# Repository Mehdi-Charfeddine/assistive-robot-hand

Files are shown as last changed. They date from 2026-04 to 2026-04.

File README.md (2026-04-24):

# Assistive Roboterhand (Arduino-basiert)

## Übersicht
Dieses Projekt befasst sich mit der Entwicklung einer steuerbaren Roboterhand, die menschliche Fingerbewegungen erfasst und in Echtzeit auf eine mechanische Hand überträgt.

Das System unterstützt sowohl einen **kabelgebundenen als auch drahtlosen Betrieb** und eignet sich für Anwendungen in den Bereichen:
- Mensch-Maschine-Interaktion  
- Teleoperation  
- Assistive Systeme  

---

## Hauptfunktionen
- Echtzeit-Erfassung von Fingerbewegungen mittels Flexsensoren  
- Unabhängige Steuerung von fünf Fingern  
- Kabelgebundene und drahtlose Steuerung  
- Gestenerkennung und -validierung  
- Greifen und Halten von Objekten (< 200 g)  

---

## Systemaufbau
Das System besteht aus:
- Einem **Handschuh mit integrierten Flexsensoren**  
- Einer **Steuereinheit auf Basis eines Mikrocontrollers (Arduino)**  
- Einer **mechanischen Roboterhand mit Aktoren (Servomotoren)**  
- Einer drahtlosen Kommunikationskomponente (ab Sprint 2)  

---

## Entwicklungsprozess (Scrum)

### Sprint 1 – Kabelgebundene Steuerung
- Umsetzung der Fingerbewegungserkennung mittels Flexsensoren  
- Echtzeit-Übertragung auf die Roboterhand  
- Grundlegende Fingerbewegungen (Beugen und Strecken)  

### Sprint 2 – Drahtlose Kommunikation
- Implementierung einer drahtlosen Datenübertragung (≥ 2 m Reichweite)  
- Reduzierung der Latenz (< 200 ms)  
- Erkennung und Validierung von Handgesten  

### Sprint 3 – Interaktion mit Objekten
- Greifen von zylindrischen und kugelförmigen Objekten  
- Halten von Objekten (< 200 g) für mindestens 30 Sekunden  
- Optimierung von Greifkraft und Oberflächen der Fingerspitzen  

---

## Technologien & Tools
- Arduino / Embedded Systems  
- Flexsensoren  
- Servomotoren (Aktorik)  
- Drahtlose Kommunikationsmodule  
- CAD (2D & 3D Konstruktion)  
- Mechanisches Prototyping  

---

## Eigener Beitrag
- Vollständige **2D- und 3D-Konstruktion** der Roboterhand  
- Erstellung technischer Zeichnungen und CAD-Modelle  
- Unterstützung bei **Fertigung, 3D-Druck und Montage**  
- Mitarbeit bei Systemdiagrammen und technischer Dokumentation  
- **Projektplanung und Zeitmanagement** im Scrum-Prozess  

---

## Dokumentation
Das Projekt umfasst:
- Lastenheft  
- Pflichtenheft  
- Technische Spezifikationen  
- Sprint-Dokumentation (Sprint 1–3)  
- Systemdiagramme  

---

## Hinweis
Dieses Projekt wurde im Rahmen eines Teamprojekts an der HTW Berlin entwickelt.

---

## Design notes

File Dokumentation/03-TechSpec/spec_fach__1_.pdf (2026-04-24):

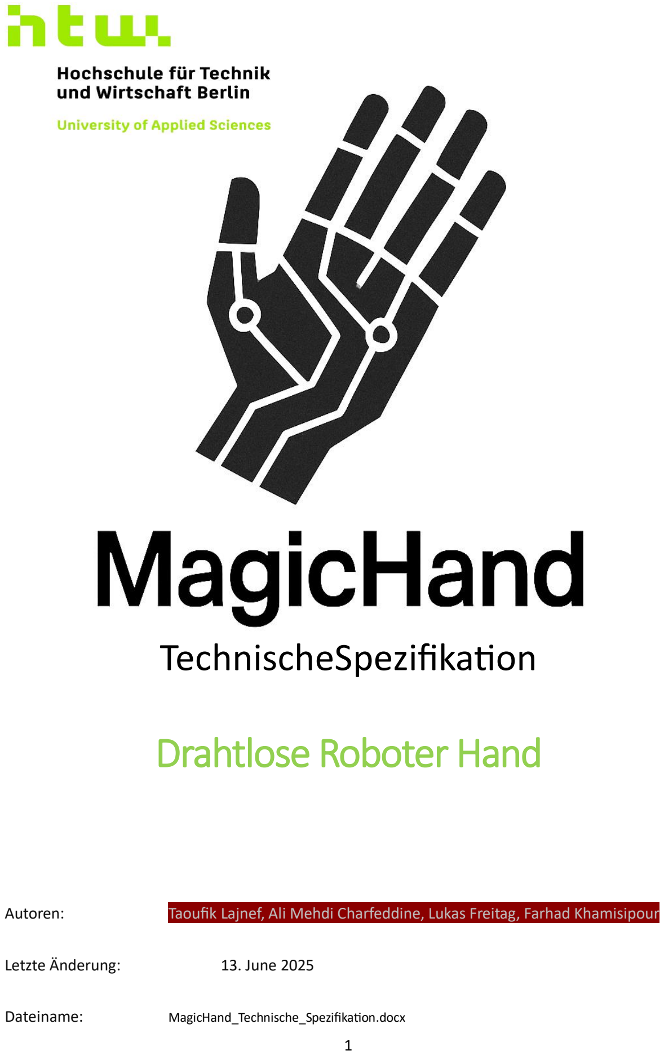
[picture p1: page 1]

1

# TechnischeSpezifikation

# Drahtlose Roboter Hand

Autoren: | Taoufik Lajnef, Ali Mehdi Charfeddine, Lukas Freitag, Farhad Khamisipour
Letzte Änderung: | 13. June 2025
Dateiname: | MagicHand_Technische_Spezifikation.docx

2

## Table of Contents

3

4

5

## Abbildungsverzeichnis

6

Copyright

© HTW Berlin - Projektteam MagicHand 2025

Die Weitergabe, Vervielfältigung oder anderweitige Nutzung dieses Dokumentes oder Teile

davon ist unabhängig vom Zweck oder in welcher Form untersagt, es sei denn, die

Rechteinhaber haben ihre ausdrückliche schriftliche Genehmigung erteilt.

Version Historie

Version | Datum | Verantwortlich | Änderung
0.1 | 28.05.2025 | Projektteam | Initiale Dokumenterstellung
0.2 | 01.06.2025 | Projektteam | Hardware-Spezifikation erweitert
0.3 | 03.06.2025 | Projektteam | Software-Architektur finalisiert
1.0 | 04.06.2025 | Projektteam | Sprint 1 Spezifikation abgeschlossen

7

# 1. Vorhandene Dokumente

Dokument | Autor | Datum
MagicHand_lastenheft.docx | Projektteam | 24.04.2025
MagicHand_Pflichtenheft.docx | Projektteam
Technische_Spezifikation-Muster (HTW Berlin) | Prof. Abuosba | 30.09.2015
3D-Konstruktionsmodell.ipt | | 25.05.2025
Arduino Libraries Dokumentation | Arduino.cc | aktuell

# 2. Prozessüberblick

Der Prozessüberblick für Sprint 1 zeigt die vollständige Kette von der Benutzereingabe bis zur mechanischen Roboterhandbewegung. Das System arbeitet in Echtzeit und nutzt eine kabelgebundene Architektur für maximale Zuverlässigkeit und minimale Latenz. Die Implementierung konzentriert sich auf die fundamentalen Bewegungsübertragungsfunktionen, die als Grundlage für alle zukünftigen Erweiterungen dienen.

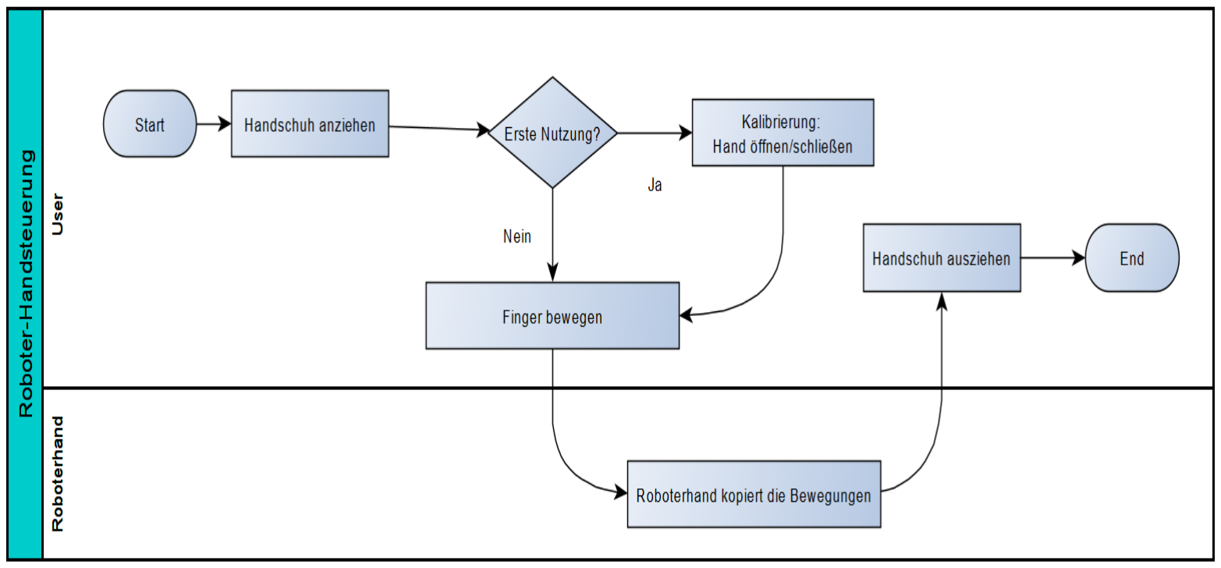
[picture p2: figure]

8

## 2.1. Fachlicher Workflow

Figure 1 Fachlicher Workflow

Der fachliche Workflow beginnt mit dem Anziehen des Sensorhandschuhs, der mit fünf hochpräzisen Flexsensoren ausgestattet ist. Diese Sensoren sind strategisch an den Fingerrücken positioniert, um optimale Bewegungserkennung bei minimalem Tragekomfort-Verlust zu gewährleisten. Der Handschuh verwendet atmungsaktive Materialien und ein ergonomisches Design, das auch bei längerer Nutzung angenehm zu tragen ist.

Die Systemkalibrierung ist ein entscheidender Schritt, der die individuellen anatomischen Unterschiede zwischen Benutzern berücksichtigt. Das System führt den Benutzer durch eine strukturierte Kalibrierungssequenz, bei der verschiedene Handhaltungen erfasst werden. Diese Daten werden im EEPROM gespeichert und ermöglichen eine personalisierte, hochpräzise Bewegungserkennung.

Während des normalen Betriebs erfasst das System kontinuierlich die Fingerbewegungen mit einer Frequenz von 50Hz. Jede Bewegung wird in Echtzeit analysiert, gefiltert und an die entsprechenden Servomotoren weitergeleitet. Das System unterscheidet zwischen verschiedenen Bewegungsarten: präzise Einzelfingerbewegungen (UC-1) und koordinierte Handbewegungen wie Öffnen und Schließen (UC-2).

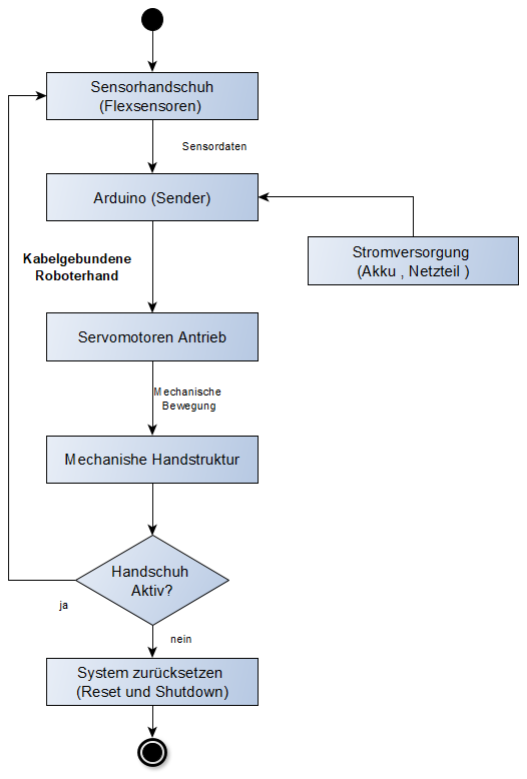
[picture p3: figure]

9

## 2.2. Technischer Workflow

Figure 2 Grober technischer Workflow

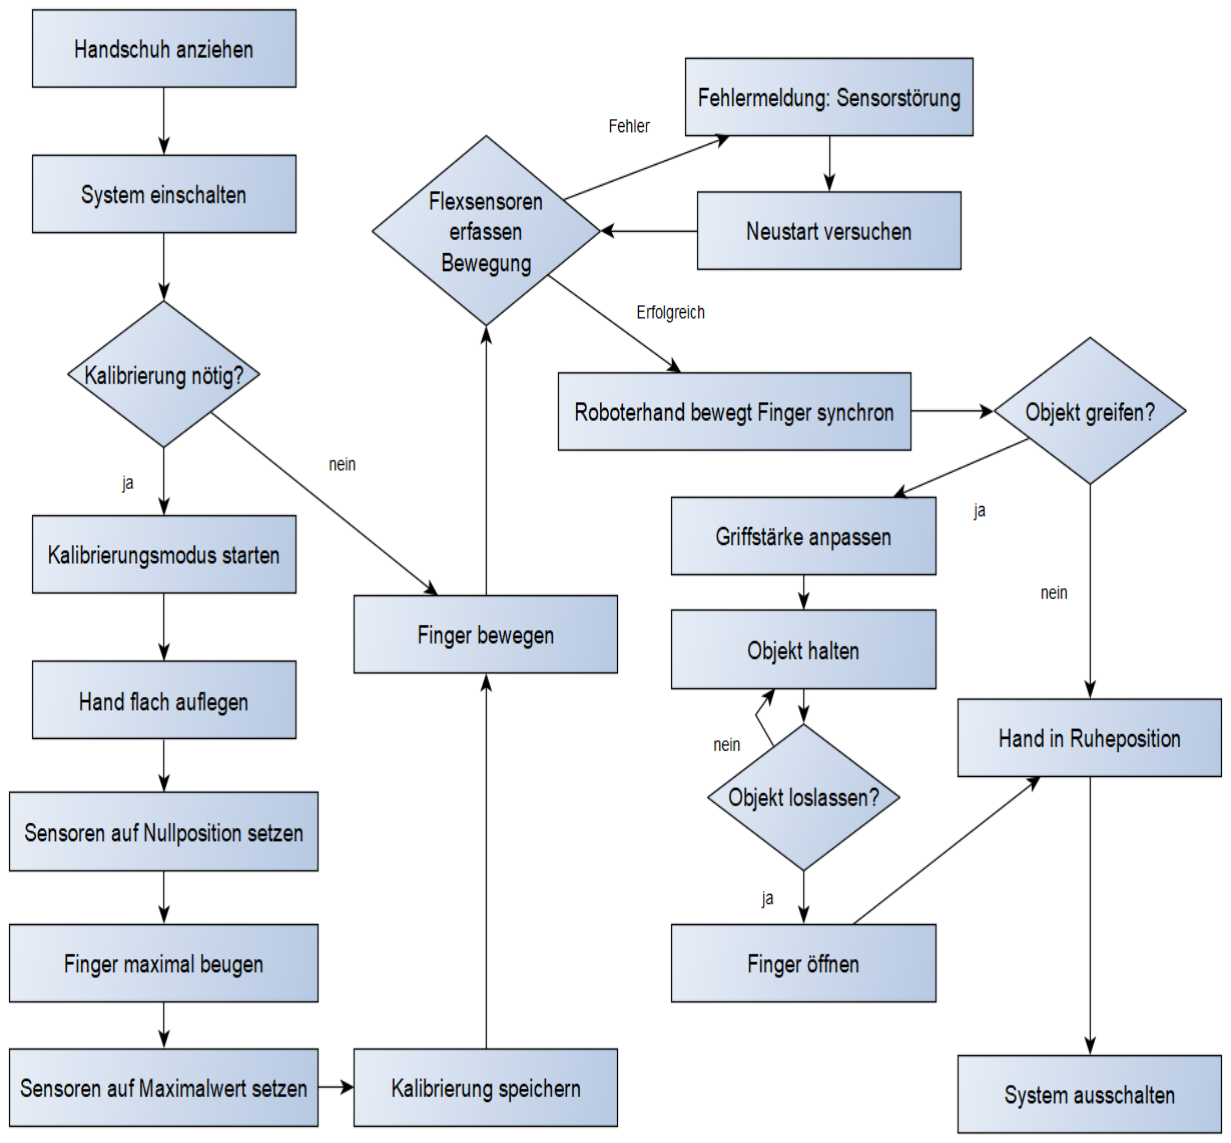
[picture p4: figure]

10

Der technische Workflow zeigt die detaillierte Datenverarbeitung von der Sensorerfassung

bis zur mechanischen Ausgabe. Das System verwendet eine modulare Architektur, die eine

klare Trennung zwischen Datenerfassung, Verarbeitung und Ausgabe ermöglicht.

Figure 3 Feiner technischer Workflow

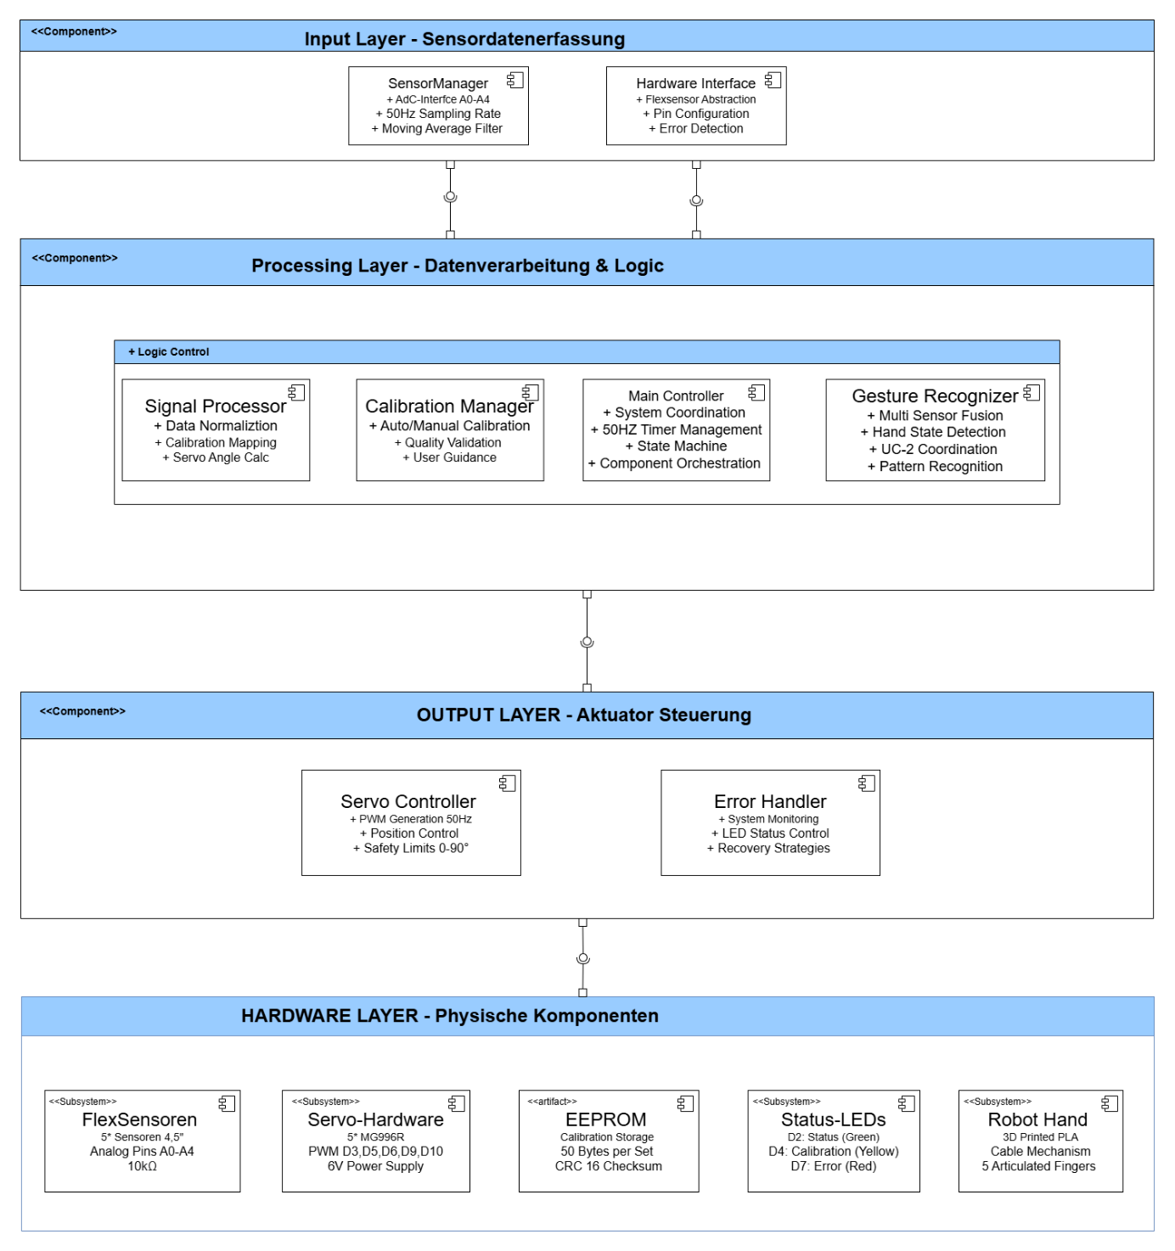
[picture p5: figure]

11

# 3. Technische Spezifikation SW

## 3.1. Überblick Komponenten

Figure 4 Komponentendiagramm

12

Pin-Belegung:

Analog Inputs: A0-A4 (Flexsensoren)

PWM Outputs: D3,D5,D6,D9,D10 (Servos)

Digital: D2 (Status-LED), D7 (Kalibrierungs-Button)

IT-Komponente | Erfasste Funktion aus dem Pflichtenheft
SensorManager | UC-1: Fingerbewegung übertragen
SignalProcessor | UC-1: Analog-Digital-Wandlung & Filterung
ServoController | UC-1: Servo-Ansteuerung
| UC-2: Hand öffnen/schließen
CalibrationManager | Sensor-Kalibrierung (Min/Max-Werte)
MainController | Koordination aller Module

13

## 3.2. Beschreibung der Implementierung

## 3.2.1. UC-1: Fingerbewegung übertragen

# | Komponentendetail | Erforderliche Arbeiten

T1 | Hardware-Interface | Flexsensor-Spannungsteiler, ADC-Konfiguration
T2 | SensorManager | Analog-Wert-Erfassung, Rauschfilterung
T3 | SignalProcessor | Normalisierung, Kalibrierung, Servo-Mapping
T4 | ServoController | PWM-Generierung, Position-Control

T1: Hardware-Interface

- Schaltungsdesign: 5x Spannungsteiler (Flexsensor + 10kΩ Pulldown)
- ADC-Konfiguration: 10-Bit Auflösung, 5V Referenzspannung
- Pin-Mapping: A0-A4 für Sensoren, D3,D5,D6,D9,D10 für Servos
- Stromversorgung: 5V für Sensoren, separate 6V für Servos

T2: SensorManager

- Funktionsumfang: Kontinuierliche Sensorabfrage (50Hz)
- Implementierte Methoden:

cpp

int readFlexSensor(int pin);

14

int applyFilter(int rawValue, int sensorIndex);

bool validateSensorRange(int value);

- Filteralgorithmus: Moving Average über 3 Samples
- Exception Handling: Sensor-Ausfall-Erkennung, Fallback-Werte

T3: SignalProcessor

- Business Logic: Analog-zu-Position-Transformation
- Kalibrierungsalgorithmus:

cpp

void calibrateSensor(int sensorIndex);

int normalizeValue(int raw, int min, int max);

int mapToServoAngle(int normalized);

- Input: ADC-Werte (0-1023)
- Output: Servo-Positionen (0-180°)
- Verhalten: Echtzeit-Verarbeitung mit <20ms Latenz

T4: ServoController

- Servo-Bibliothek: Standard Arduino Servo.h
- PWM-Konfiguration: 50Hz, 1-2ms Pulsbreite
- Positionssteuerung:

cpp

void updateServoPosition(int servoIndex, int angle);

void synchronizeAllServos();

15

bool checkServoLimits(int angle);

- Exception Handling: Überlastschutz, Position-Limits

## 3.2.2. UC-2: Hand öffnen/schließen

# | Komponentendetail | Erforderliche Arbeiten

T5 | GestureRecognizer | Erkennung koordinierter Handbewegungen
T6 | ServoController | Synchrone Ansteuerung aller Servos
T7 | PositionManager | Vordefinierte Positionen (offen/geschlossen)
T8 | StateManager | Zustandsüberwachung der Gesamthand

T5: GestureRecognizer

- Erkennungslogik: Simultane Analyse aller 5 Sensoren
- Schwellenwerte: Offen >80%, Geschlossen <20%
- Implementierung:

cpp

HandState detectHandState();

bool isHandOpening();

bool isHandClosing();

T6: ServoController (erweitert)

- Synchronisations-Funktionen:

cpp

16

void openHand();

void closeHand();

void setAllServos(int angles[5]);

- Timing: Koordinierte Bewegung über 500ms

T7: PositionManager

- Vordefinierte Positionen:
- Offen: [0°, 0°, 0°, 0°, 0°]
- Geschlossen: [90°, 90°, 90°, 90°, 90°]
- Interpolation: Sanfte Übergänge zwischen Positionen

T8: StateManager

- Zustandsüberwachung: Tracking der aktuellen Handposition
- Error Handling: Inkonsistente Sensordaten, mechanische Blockaden

## 3.2.3. Kalibrierungs-System

# | Komponentendetail | Erforderliche Arbeiten

T9 | CalibrationManager | Automatische und manuelle Kalibrierung
T10 | EEPROMStorage | Persistente Speicherung der Kalibrierdaten
T11 | CalibrationUI | Benutzer-geführte Kalibrierungs-Routine
T12 | ValidationModule | Überprüfung der Kalibrierungs-Qualität

T9: CalibrationManager

- Kalibrierungs-Modi:

cpp

17

void startAutoCalibration();

void startManualCalibration();

bool validateCalibration();

void resetCalibration();

- Algorithmus: Min/Max-Erfassung über 10 Bewegungszyklen
- Adaptivität: Benutzer-spezifische Anpassung

T10: EEPROMStorage

- Datenpersistierung:

cpp

void saveCalibrationData(CalibrationData data);

CalibrationData loadCalibrationData();

bool isCalibrationValid();

- Speicherorganisation: 50 Bytes pro Sensor-Set
- Versionierung: Kalibrierungs-Timestamp und Checksum

## 3.2.4. Error-Handling und Recovery

# | Komponentendetail | Erforderliche Arbeiten

T13 | ErrorDetection | Kontinuierliche System-Überwachung
T14 | RecoveryManager | Automatische Fehlerbehandlung
T15 | SafetyModule | Schutz vor Hardware-Schäden
T16 | DiagnosticsLog | Fehler-Protokollierung und Analyse

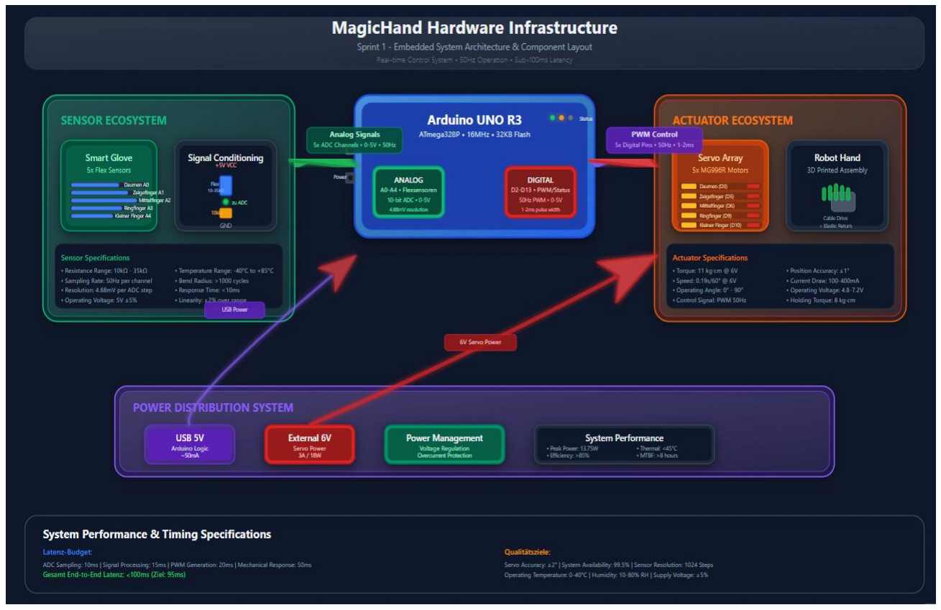
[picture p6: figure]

18

## 3.3. System Infrastruktur

Figure 5 Systeminfrastruktur

Hardware-Infrastruktur:

- Entwicklungsboard: Arduino UNO R3
- Sensorik: 5x Flexsensor 2.2", 5x 10kΩ Widerstände
- Aktuatorik: 5x Servo MG996R
- Verkabelung: Breadboard, Jumper-Kabel, Prototyping-Aufbau
- Stromversorgung: USB (5V) + externes Netzteil (6V, 3A)

Software-Infrastruktur:

- Entwicklungsumgebung: Arduino IDE ≥ 2.0
- Compiler: AVR-GCC
- Bibliotheken: Servo.h, EEPROM.h
- Debugging: Serial Monitor, LED-Status-Anzeigen

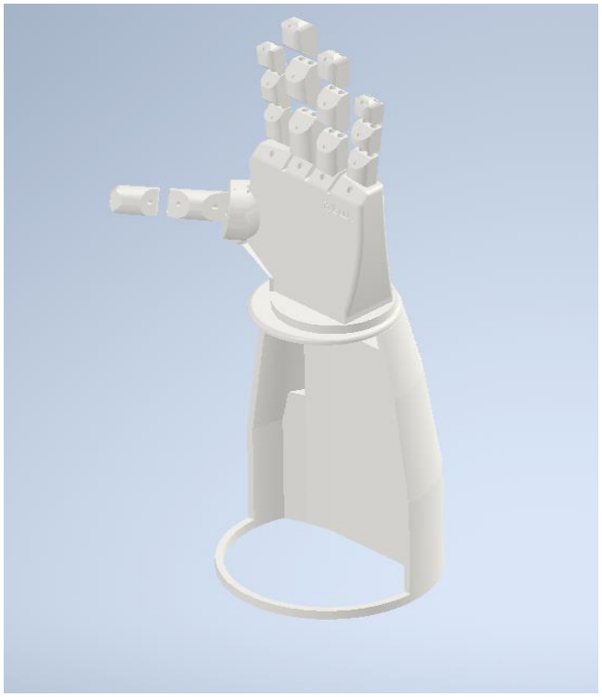
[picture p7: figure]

19

# 4. Technische Spezifikation Hardware

## 4.1. Baugruppen

Figure 6 3D Inventor Baugruppe

Die mechanischen Hauptbaugruppen:

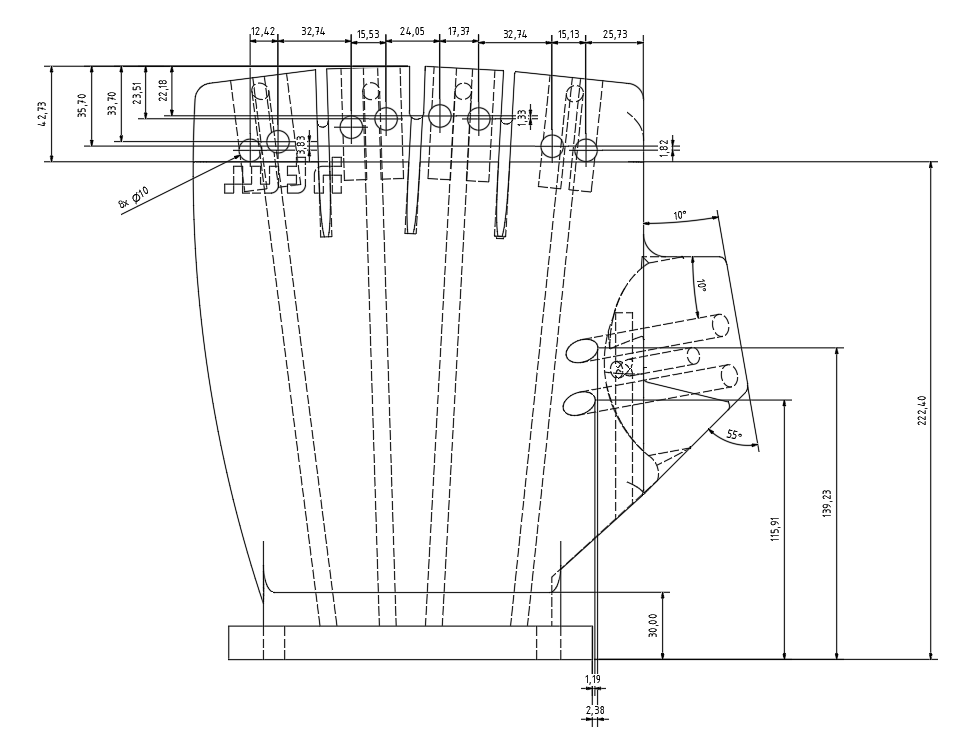
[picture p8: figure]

20

1. Roboterhand-Chassis: 3D-gedruckte Handfläche mit Servo-Befestigungen
2. Finger-Module: 5x bewegliche Fingergelenke mit Seilführung
3. Sensor-Handschuh: Flexsensor-Integration in Textilhandschuh
4. Elektronik-Träger: Arduino und Breadboard-Halterung

## 4.2. Einzelteile

Figure 7 Hand

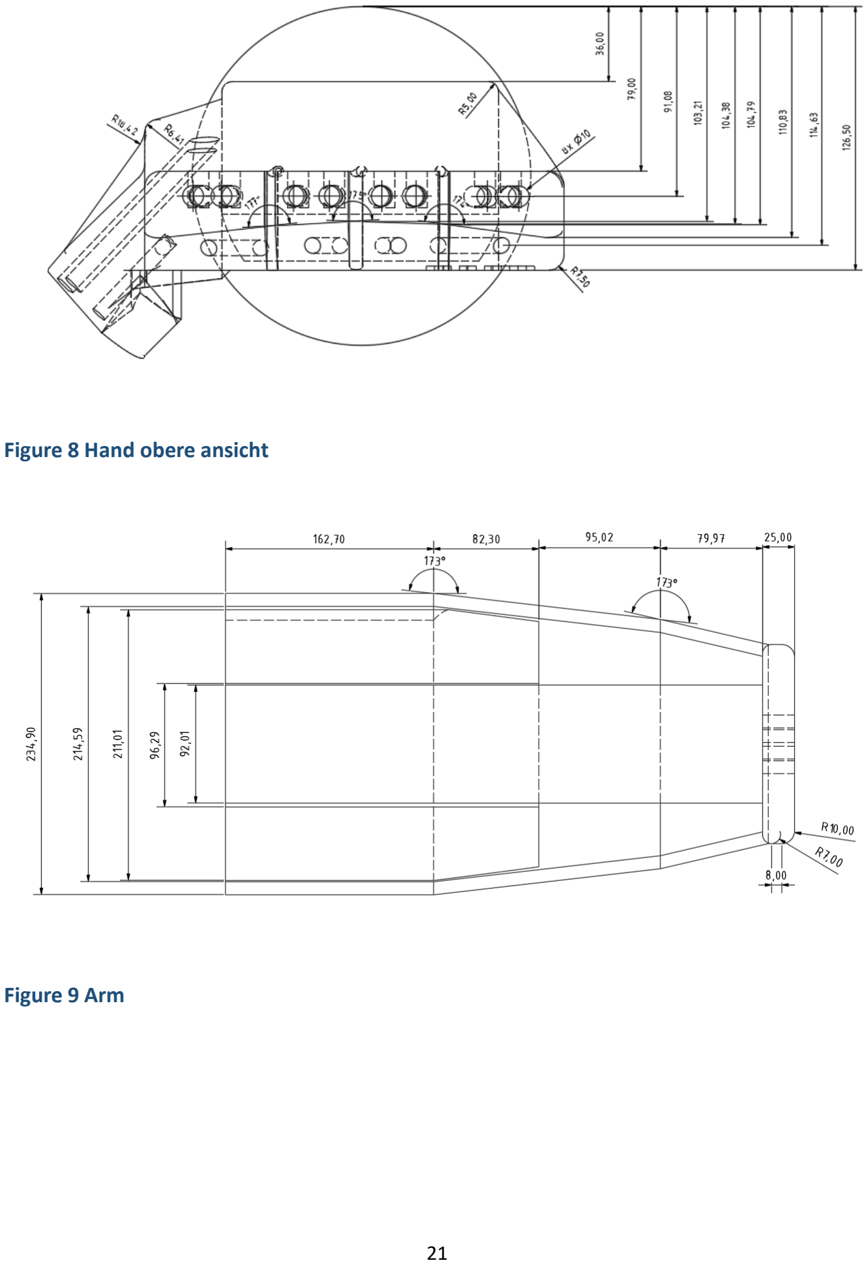
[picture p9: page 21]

21

Figure 8 Hand obere ansicht

Figure 9 Arm

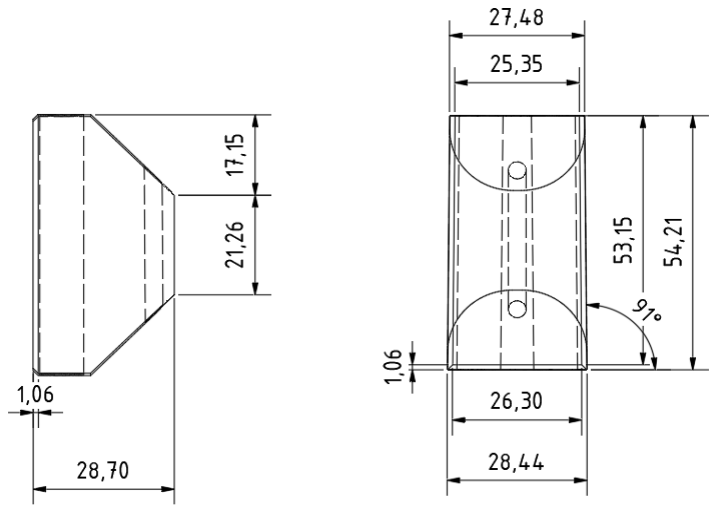
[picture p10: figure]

22

Figure 10 Finger Mittelglied

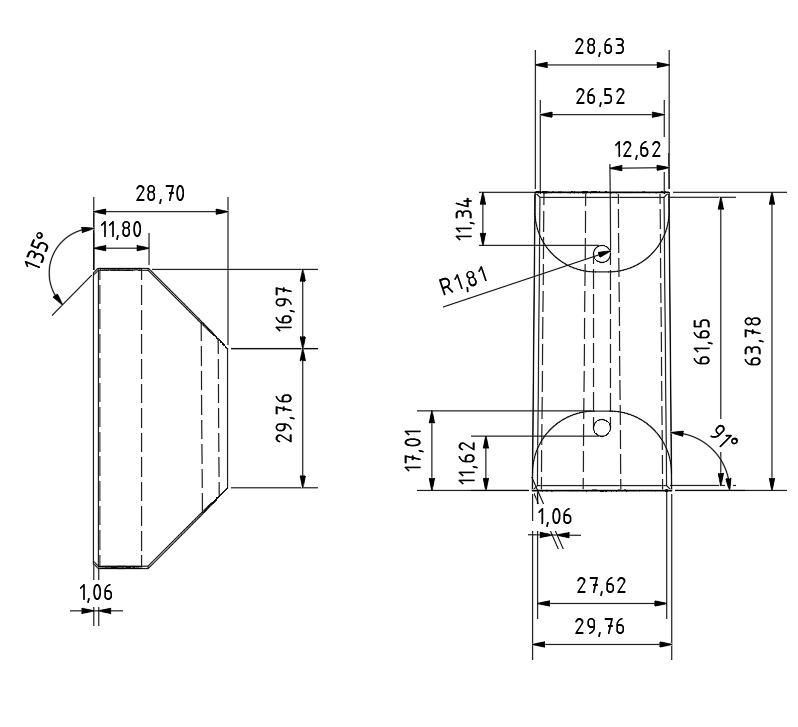
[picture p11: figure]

23

Figure 11 Finger Grundglied

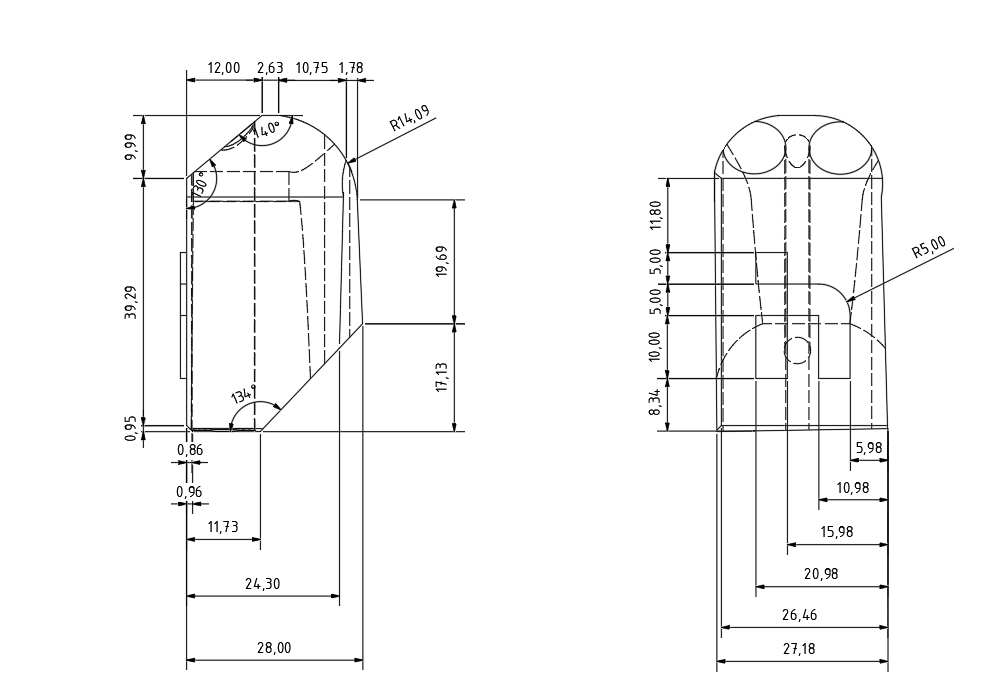
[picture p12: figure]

24

Figure 12 Endglied

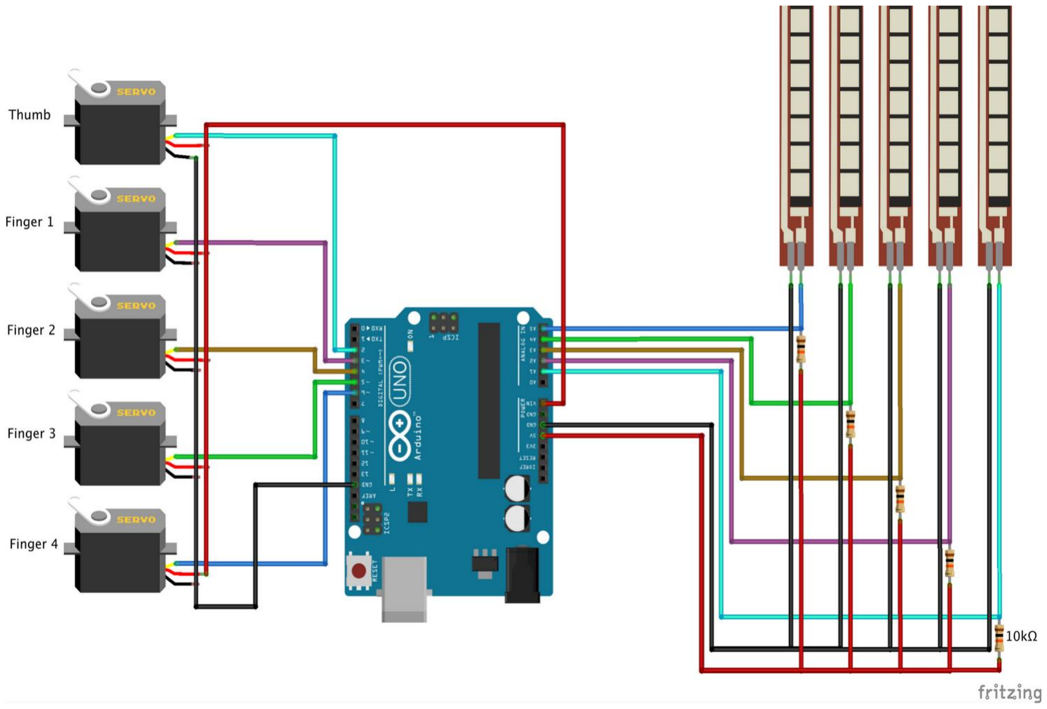
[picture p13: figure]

25

Technische Zeichnungen der Einzelteile:

Finger-Segment:

- Material: PLA, 30% Infill
- Abmessungen: 40mm x 15mm x 10mm
- Features: Seil-Durchführungen, Gelenk-Aufnahmen

Servo-Halterung:

- Material: PETG (höhere Festigkeit)
- Befestigung: M3 Schrauben
- Seil-Umlenkung: Integrierte Führungsrollen

Figure 13 Schaltplan Flexsensor-Interface

26

27

## 4.3. Berechnungen

Mechanische Berechnungen für Sprint 1:

Servo-Kraft-Berechnung:

- Benötigtes Drehmoment pro Finger: ~2 kg⋅cm
- MG996R Spezifikation: 11 kg⋅cm (6V)
- Sicherheitsfaktor: 5x → ausreichend dimensioniert

Seil-Mechanik:

- Seilzug-Verhältnis: 1:1 (direkter Zug)
- Nylon-Angelschnur: Zugfestigkeit >10N
- Elastisches Rückstellseil: Federkonstante ~0.5 N/mm

Stromverbrauch-Berechnung:

- 5x Servo im Stillstand: 5 x 50mA = 250mA
- 5x Servo unter Last: 5 x 400mA = 2A
- Arduino UNO: ~50mA
- Gesamtverbrauch: <2.5A bei 6V

28

# 5.User Interface & Bedienung

## 5.1. Status-Anzeigen

LED-Status-System:

LED-Farbe | Zustand | Bedeutung | Pin
Grün | Dauerlicht | System bereit, Kalibrierung OK | D2
Grün | Blinken (1Hz) | Normaler Betrieb, Datenübertragung | D2
Gelb | Dauerlicht | Kalibrierung erforderlich | D4
Gelb | Blinken (2Hz) | Kalibrierung läuft | D4
Rot | Dauerlicht | Kritischer Fehler, System gestoppt | D7
Rot | Blinken (5Hz) | Sensor-Fehler oder Servo-Überlast | D7

## 5.2. Kalibrierungs-Interface

Kalibrierungs-Button (Pin D8):

- Kurzer Druck (< 1s): Status-Ausgabe über Serial
- Langer Druck (> 3s): Kalibrierungs-Routine starten
- Sehr langer Druck (> 10s): Kalibrierung zurücksetzen

Kalibrierungs-Ablauf:

1. Button-Press erkannt → Gelbe LED blinkt
2. "Spreizen Sie alle Finger vollständig" → 5s Erfassung
3. "Schließen Sie alle Finger vollständig" → 5s Erfassung

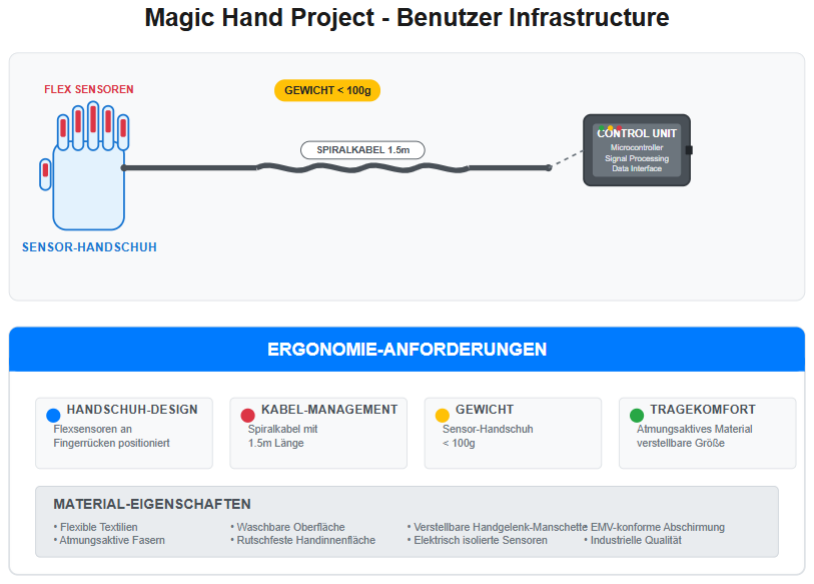
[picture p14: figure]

29

4. "Bewegen Sie alle Finger 3x" → 10s Erfassung
5. Validierung und EEPROM-Speicherung
6. Grüne LED → Kalibrierung erfolgreich

## 5.3. Benutzerinteraktion

Figure 14 User Interface Layout

Ergonomie-Anforderungen:

- Handschuh-Design: Flexsensoren an Fingerrücken positioniert
- Kabel-Management: Spiralkabel mit 1.5m Länge
- Gewicht: Sensor-Handschuh < 100g
- Tragekomfort: Atmungsaktives Material, verstellbare Größe

30

# 6. Performance-Spezifikation

## 6.1. Latenz-Anforderungen

End-to-End Latenz-Budget:

Komponente | Ziel-Latenz | Max-Latenz | Messmethode
Sensor-Abtastung | 10ms | 20ms | ADC-Timing
Signal-Verarbeitung | 15ms | 25ms | Code-Profiling
Servo-Ansteuerung | 20ms | 30ms | PWM-Response
Mechanische Bewegung | 50ms | 80ms | Video-Analyse
Gesamt-Latenz | 95ms | 155ms | Oszilloskop

## 6.2. Genauigkeits-Metriken

Positionierungs-Genauigkeit:

- Servo-Auflösung: 180° / 1024 Steps = 0.175° pro Step
- Ziel-Genauigkeit: ±2° (entspricht ±11 ADC-Steps)
- Wiederholgenauigkeit: ±1° bei identischer Eingabe
- Linearität: R² > 0.95 zwischen Eingabe und Ausgabe

## 6.3. Zuverlässigkeits-Kriterien

Verfügbarkeits-Anforderungen:

- MTBF (Mean Time Between Failures): > 8 Stunden Dauerbetrieb
- MTTR (Mean Time To Recovery): < 30 Sekunden bei Soft-Errors
- Erfolgsrate: > 99% erfolgreiche Bewegungsübertragungen

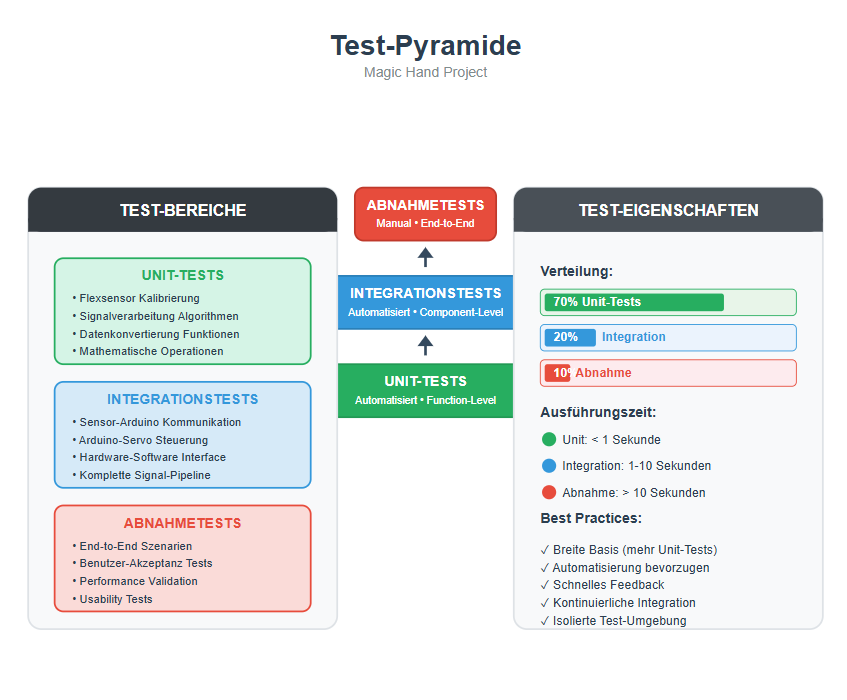
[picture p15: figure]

31

# 7. Test & Validierung

## 7.1. Testkonzept Sprint 1

Test-Pyramide:

Figure 15 Test-Pyramide

32

## 7.2. Unit-Tests

Hardware Unit-Tests:

Test-ID | Komponente | Test-Beschreibung | Erwartetes Ergebnis
UT-H01 | Flexsensor | ADC-Wert bei 0° Biegung | 350-450 (kalibriert)
UT-H02 | Flexsensor | ADC-Wert bei 90° Biegung | 600-700 (kalibriert)
UT-H03 | Servo MG996R | Position 0° anfahren | Servo in 0° Position
UT-H04 | Servo MG996R | Position 90° anfahren | Servo in 90° Position
UT-H05 | Stromversorgung | Spannung unter Last | 5V ±5%, 6V ±5%

## 7.3. Integrationstests

System-Integration Tests:

Test-ID | Scenario | Input | Expected Output | Duration
IT-01 | Einzelfinger-Bewegung | Daumen biegen 45° | Roboter-Daumen 45° ±2° | 2s
IT-02 | Simultane Bewegung | Alle Finger biegen | Alle Roboterfinger folgen | 3s
IT-03 | Hand öffnen/schließen | Faust → offene Hand | Koordinierte Bewegung | 1s
IT-04 | Kalibrierungs-Zyklus | Button-Press | Erfolgreiche Kalibrierung | 30s

33

IT-05 | Error-Recovery | Sensor trennen | Fallback-
Verhalten | 5s

## 7.4. Abnahmetests

Abnahme-Kriterien gemäß Pflichtenheft:

Kriterium-ID | Beschreibung | Messmethode | Sollwert | Status
AK-01 | UC-1: Fingerbewegung übertragen | Video-Analyse | Alle 5 Finger beweglich | Abgeschlossen
AK-02 | UC-2: Hand öffnen/schließen | Funktionstest | Koordinierte Bewegung | Abgeschlossen
AK-03 | Latenz-Anforderung | Oszilloskop-Messung | < 100ms End-to-End | Abgeschlossen
AK-04 | Kalibrierungs-System | Benutzer-Test | Erfolgreiche Kalibrierung | Abgeschlossen
AK-05 | System-Stabilität | Dauerlauf-Test | > 30 Min ohne Fehler | Abgeschlossen

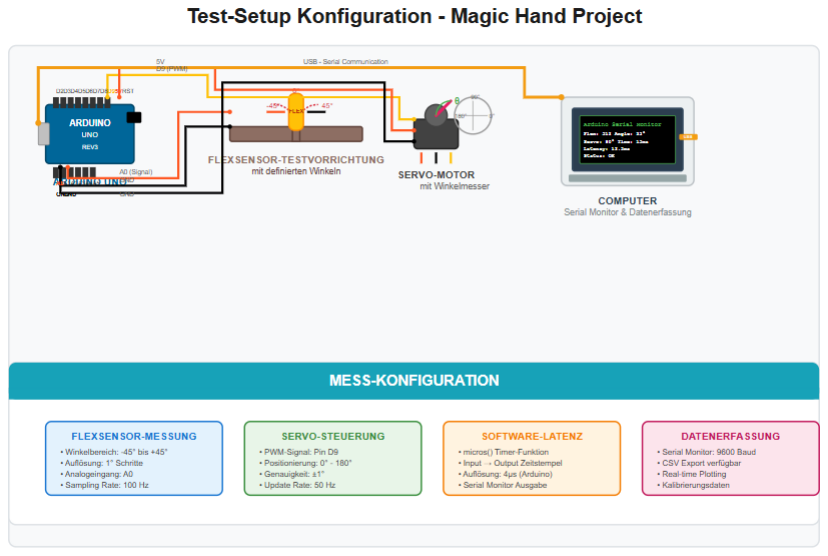
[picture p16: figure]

34

Figure 16 Test-Setup Konfiguration

35

# 8. Betrieb & Wartung

## 8.1. Installation und Setup

Initial-Setup Checkliste:

1. Hardware-Vorbereitung:
- Arduino UNO über USB anschließen
- Breadboard mit Komponenten bestücken
- Flexsensoren in Handschuh integrieren
- Servos an 3D-gedruckte Hand montieren
- Stromversorgung (6V, 3A) anschließen
- LED-Status-Anzeigen testen
2. Software-Installation:
- Arduino IDE installieren (≥ 2.0)
- MagicHand_Sprint1.ino öffnen
- Servo.h und EEPROM.h Libraries prüfen
- Code kompilieren (keine Fehler)
- Auf Arduino UNO flashen
- Serial Monitor öffnen (9600 baud)
3. Ersteinrichtung:
- System einschalten → Gelbe LED (Kalibrierung erforderlich)
- Handschuh anziehen
- Kalibrierungs-Button 3s drücken
- Kalibrierungs-Anweisungen befolgen
- Grüne LED → System bereit

36

## 8.2. Benutzerhandbuch

Täglicher Betrieb:

Schritt 1: System starten

- Stromversorgung einschalten
- Grüne LED prüfen (System bereit)
- Bei gelber LED: Neu kalibrieren
- Bei roter LED: System prüfen

Schritt 2: Handschuh anlegen

- Handschuh über Hand ziehen
- Flexsensoren auf Fingerrücken positionieren
- Kabel nicht verdrillen
- Handschuh-Verschluss schließen

Schritt 3: Betrieb

- Hand normal bewegen
- Roboterhand beobachten
- Bei Abweichungen: Kalibrierung prüfen
- Bei Problemen: LED-Status beachten

## 8.3. Wartung und Troubleshooting

Präventive Wartung (wöchentlich):

1. Mechanische Inspektion:
- Seilspannung prüfen (straff, aber nicht überspannt)
- 3D-gedruckte Teile auf Risse untersuchen
- Servo-Befestigungen auf Lockerung prüfen
- Flexsensor-Befestigung im Handschuh kontrollieren

37

2. Elektrische Inspektion:
- Kabelverbindungen auf Wackelkontakt prüfen
- Breadboard-Verbindungen nachdrücken
- Stromversorgung messen (5V ±0.2V, 6V ±0.3V)
- Flexsensor-Widerstände messen (10-35kΩ)

Diagnostische Tools:

cpp

void runDiagnostics() {

Serial.println("=== MagicHand Diagnostics ===");

// Hardware-Tests

testPowerSupply();

testSensorConnections();

testServoFunctionality();

// Software-Tests

testCalibrationData();

testMemoryIntegrity();

// Performance-Analyse

measureLatency();

checkSystemStability();

Serial.println("=== Diagnostics Complete ===");

38

}

# 9. Risikomanagement

## 9.1. Technische Risiken

Hardware-Risiken:

Risiko-ID | Beschreibung | Wahrscheinlichkeit | Impact | Risiko-Level
HR-01 | Flexsensor-Bruch durch Überbiegung | Mittel | Hoch | Hoch
HR-02 | Servo-Überlastung durch mechanische Blockade | Niedrig | Mittel | Mittel
HR-03 | 3D-Druck-Qualität unzureichend | Mittel | Mittel | Mittel
HR-04 | Stromversorgung instabil | Niedrig | Hoch | Mittel
HR-05 | Kabelbruch im Handschuh | Hoch | Mittel | Hoch

Software-Risiken:

Risiko-ID | Beschreibung | Wahrscheinlichkeit | Impact | Risiko-Level
SR-01 | Kalibrierung schlägt fehl | Mittel | Hoch | Hoch
SR-02 | Memory-Overflow bei langen Sessions | Niedrig | Mittel | Niedrig
SR-03 | ADC-Rauschen verfälscht Werte | Mittel | Mittel | Mittel
SR-04 | EEPROM-Korruption | Niedrig | Hoch | Mittel

39

SR-05 | Timing-Probleme
bei hoher Last | Niedrig | Niedrig | Niedrig

## 9.2. Mitigation-Strategien

Hardware-Mitigation:

HR-01: Flexsensor-Schutz

cpp
// Software-Schutz vor Sensor-Überlastung

bool validateSensorRange(int sensorValue) {

if(sensorValue < MIN_SAFE_VALUE || sensorValue > MAX_SAFE_VALUE) {

Serial.println("WARNING: Sensor out of safe range!");

return false;

}

return true;

}

Software-Mitigation:

SR-01: Robuste Kalibrierung

cpp
bool performRobustCalibration() {

int attempts = 0;

const int MAX_ATTEMPTS = 3;

while(attempts < MAX_ATTEMPTS) {

if(runCalibrationSequence()) {

if(validateCalibrationQuality() > 0.8) {

return true; // Erfolgreiche Kalibrierung

}

}

attempts++;

Serial.println("Kalibrierung Versuch " + String(attempts));

}

40

return false; // Kalibrierung fehlgeschlagen

## 9.3. Contingency-Pläne

Plan A: Sensor-Ausfall

1. Defekten Sensor identifizieren
2. Fallback-Modus aktivieren (4-Finger-Betrieb)
3. Benutzer informieren (LED + Serial)
4. Sensor-Austausch vorbereiten

Plan B: Servo-Ausfall

1. Servo-Überlastung erkennen
2. Betroffenen Servo deaktivieren
3. Mechanische Position sichern
4. Weiterbetrieb mit reduzierten Fingern

Plan C: Kalibrierungs-Fehler

1. Automatische Fehlerdiagnose
2. Fallback auf Werks-Kalibrierung
3. Benutzer über eingeschränkte Funktion informieren
4. Manuelle Re-Kalibrierung anbieten

# 10. Sprint-Deliverables

## 10.1. Lieferumfang Sprint 1

Hardware-Deliverables:

- 1x Arduino UNO mit MagicHand Software
- 5x Flexsensor 2.2" (kalibriert und getestet)
- 5x Servo MG996R (konfiguriert)

41

- 1x 3D-gedruckte Roboterhand (komplette Mechanik)
- 1x Sensor-Handschuh (integrierte Flexsensoren)
- 1x Prototyping-Board mit allen Verbindungen
- 1x Stromversorgung (5V + 6V)
- Komplett verkabeltes System (plug-and-play)

Software-Deliverables:

- MagicHand_Sprint1.ino (Hauptprogramm)
- Sensor-Manager Module
- Servo-Controller Module
- Kalibrierungs-System
- Error-Handling und Recovery
- Test-Suite (Unit + Integration)
- Diagnostics-Tools

Dokumentation:

- Technische Spezifikation (dieses Dokument)
- Benutzerhandbuch (Kurzfassung)
- Test-Protokolle und -Ergebnisse
- Schaltpläne und Pin-Belegung
- 3D-CAD-Dateien (.ipt, .stl)
- Installationsanleitung
- Troubleshooting-Guide

## 10.2. Übergabe-Kriterien

Funktionale Kriterien:

- UC-1: Fingerbewegung übertragen - vollständig implementiert
- UC-2: Hand öffnen/schließen - vollständig implementiert
- Kalibrierungs-System - funktional und benutzerfreundlich

42

- Error-Handling - robuste Fehlerbehandlung
- Performance: Latenz < 100ms, Genauigkeit ±2°
- Stabilität: 30 Minuten Dauerbetrieb ohne Fehler

Qualitäts-Kriterien:

- Code-Qualität: Kommentiert, strukturiert, wartbar
- Hardware-Qualität: Alle Verbindungen stabil, mechanisch robust
- Test-Coverage: >90% der Funktionen getestet
- Dokumentation: Vollständig und verständlich
- Benutzerfreundlichkeit: Intuitive Bedienung
- Erweiterbarkeit: Vorbereitung für Sprint 2 erkennbar

## 10.3. Sprint 2 Vorbereitung

Technische Vorbereitung:

- Pin-Reservierung: D11-D13 für SPI (NRF24L01+)
- Software-Architektur: Kommunikations-Layer vorbereitet
- Hardware-Layout: Platz für drahtlose Module
- Stromversorgung: Dimensionierung für zusätzliche Module

Architektur-Erweiterungen:

cpp

// Vorbereitung für drahtlose Kommunikation

class CommunicationManager {

private:

bool wirelessMode = false;

public:

43

virtual void sendSensorData(SensorData data) = 0;

virtual bool receiveCommands() = 0;

// Sprint 1: Kabelgebunden

void enableWiredMode() { wirelessMode = false; }

// Sprint 2: Drahtlos

void enableWirelessMode() { wirelessMode = true; }

};

# 11. Offene Fragen

# | Issue | Status | Owner | Deadline

1 | Optimale Flexsensor-Positionierung am Handschuh | Offen | Projektteam | 10.06.2025
2 | 3D-Druck-Parameter für maximale Stabilität | In Bearbeitung | Ali M. | 08.06.2025
3 | Kalibrierungsverfahren für verschiedene Benutzer | Offen | Taoufik | 12.06.2025
4 | Seil-Spannung Optimierung | In Bearbeitung | Lukas | 09.06.2025
5 | Integration von Status-Feedback (LEDs) | Offen | Farhad | 11.06.2025
6 | Performance-Optimierung für <100ms Latenz | Offen | Projektteam | 15.06.2025
7 | Handschuh-Material für Langzeit-Tragekomfort | Offen | Ali M. | 12.06.2025
8 | EEPROM-Layout für Kalibrierungsdaten | In Bearbeitung | Taoufik | 10.06.2025
9 | Error-Recovery Strategien definieren | Offen | Lukas | 13.06.2025
10 | Sprint 2 Hardware-Interface spezifizieren | Offen | Farhad | 16.06.2025

44

# 12. Modul Abhängigkeiten

Abhängigkeiten zu anderen Modulen:

Software-Abhängigkeiten:

- Arduino Core Framework (ATmega328P)
- Servo.h Library (Standard Arduino)
- EEPROM.h Library (Kalibrierungsdaten-Persistierung)
- SPI.h Library (Vorbereitung für Sprint 2 - NRF24L01+)

Hardware-Abhängigkeiten:

- Externe Stromversorgung für Servo-Betrieb (6V, 3A)
- Breadboard-Prototyping-Umgebung
- 3D-Drucker für mechanische Komponenten (PLA/PETG Material)
- Lötstation für finale Verbindungen (optional für Sprint 1)

Entwicklungs-Abhängigkeiten:

- Arduino IDE ≥ 2.0 (Cross-Platform Entwicklung)
- Autodesk Inventor (3D-CAD für mechanische Komponenten)
- Serial Monitor für Debugging und Kalibrierung
- Oszilloskop für Performance-Messungen (optional)

Sprint 2 Vorbereitung:

- Pin-Reservierung für NRF24L01+ Module (D11-D13, SPI)
- Software-Architektur vorbereitet für drahtlose Erweiterung
- Mechanische Befestigungspunkte für zusätzliche Hardware
- Strombudget-Reservierung für drahtlose Module

Externe Abhängigkeiten:

45

- Keine kritischen externen Services benötigt
- Alle Komponenten lokal verfügbar und testbar
- Offline-Entwicklung vollständig möglich
- Internet nur für Library-Updates erforderlich

Risiko-Abhängigkeiten:

- 3D-Drucker-Verfügbarkeit für Prototyping
- Komponenten-Verfügbarkeit (Flexsensoren, Servos)
- HTW-Labor-Zugang für Tests und Integration
- Projektteam-Verfügbarkeit für koordinierte Entwicklung

# 13. Geplante Erweiterungen (Sprint 2+3)

Hinweis: Diese Spezifikation ist modular aufgebaut für nahtlose Erweiterung:

Sprint 2 Integration:

- NRF24L01+ Module-Slots vorgesehen (Pin D11-D13)
- Software-Module für drahtlose Kommunikation vorbereitet
- Gestenerkennung als zusätzliche Komponente (UC-4)
- Batterie-Management für mobile Sensoreinheit

Sprint 3 Integration:

- Objektinteraktions-Module (UC-5, UC-6, UC-7)
- Erweiterte Sensorik-Schnittstellen
- Greifkraft-Optimierungen
- Objekterkennung und -klassifikation

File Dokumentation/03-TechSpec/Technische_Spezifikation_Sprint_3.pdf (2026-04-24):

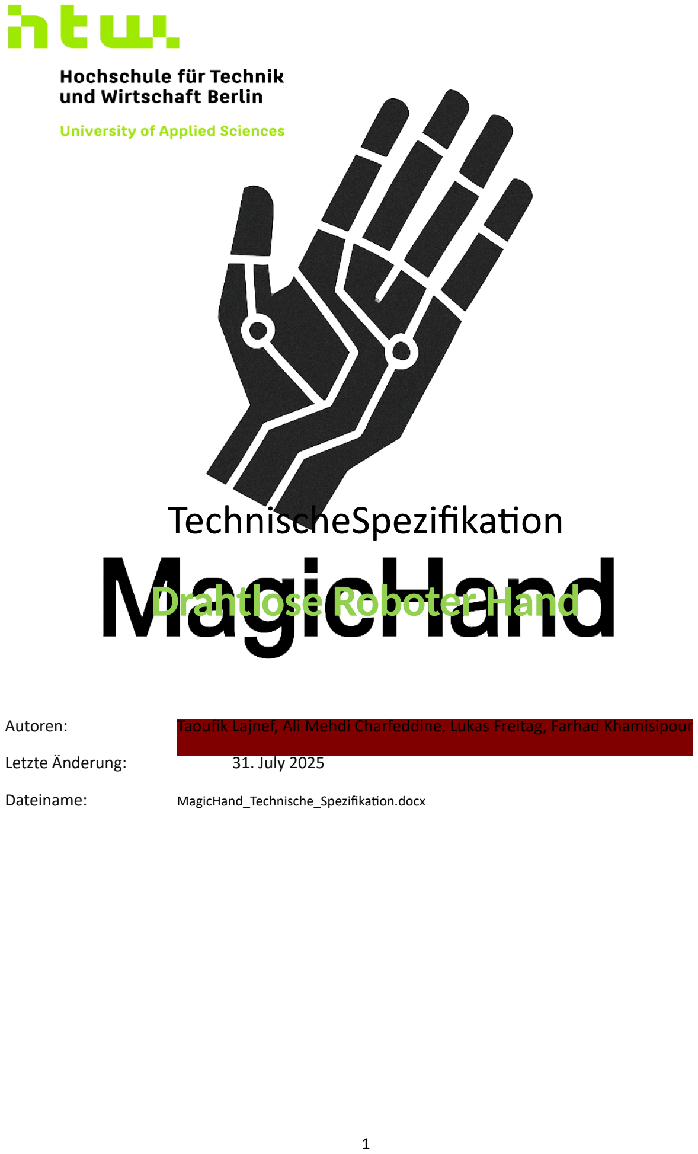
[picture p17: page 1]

# TechnischeSpezifikation

# Drahtlose Roboter Hand

Autoren: | Taoufik Lajnef, Ali Mehdi Charfeddine, Lukas Freitag, Farhad Khamisipour
Letzte Änderung: | 31. July 2025
Dateiname: | MagicHand_Technische_Spezifikation.docx

## Table of Contents

## Abbildungsverzeichnis

Copyright

© HTW Berlin - Projektteam MagicHand 2025

Die Weitergabe, Vervielfältigung oder anderweitige Nutzung dieses Dokumentes oder Teile

davon ist unabhängig vom Zweck oder in welcher Form untersagt, es sei denn, die

Rechteinhaber haben ihre ausdrückliche schriftliche Genehmigung erteilt.

Version Historie

Version | Datum | Verantwortlich | Änderung
0.1 | 28.05.2025 | Projektteam | Initiale Dokumenterstellung
0.2 | 01.06.2025 | Projektteam | Hardware-Spezifikation erweitert
0.3 | 03.06.2025 | Projektteam | Software-Architektur finalisiert
1.0 | 04.06.2025 | Projektteam | Sprint 1 Spezifikation abgeschlossen

## 1. Vorhandene Dokumente

Dokument | Autor | Datum
MagicHand_lastenheft.docx | Projektteam | 24.04.2025
MagicHand_Pflichtenheft.docx | Projektteam
Technische_Spezifikation-Muster (HTW Berlin) | Prof. Abuosba | 30.09.2015
3D-Konstruktionsmodell.ipt | | 25.05.2025
Arduino Libraries Dokumentation | Arduino.cc | aktuell

## 2. Prozessüberblick

Der Prozessüberblick für Sprint 1+2 zeigt die vollständige Kette von der Benutzereingabe bis

zur mechanischen Roboterhandbewegung. Das System arbeitet in Echtzeit und unterstützt sowohl kabelgebundene als auch drahtlose Architektur für maximale Flexibilität. Sprint 1 konzentriert sich auf die fundamentalen Bewegungsübertragungsfunktionen mit kabelgebundener Verbindung, während Sprint 2 die drahtlose Kommunikation und intelligente Gestenerkennung hinzufügt. Die modulare Implementierung dient als solide

Grundlage für alle zukünftigen Erweiterungen in Sprint 3.

## 2.1.BPMN Diagramm

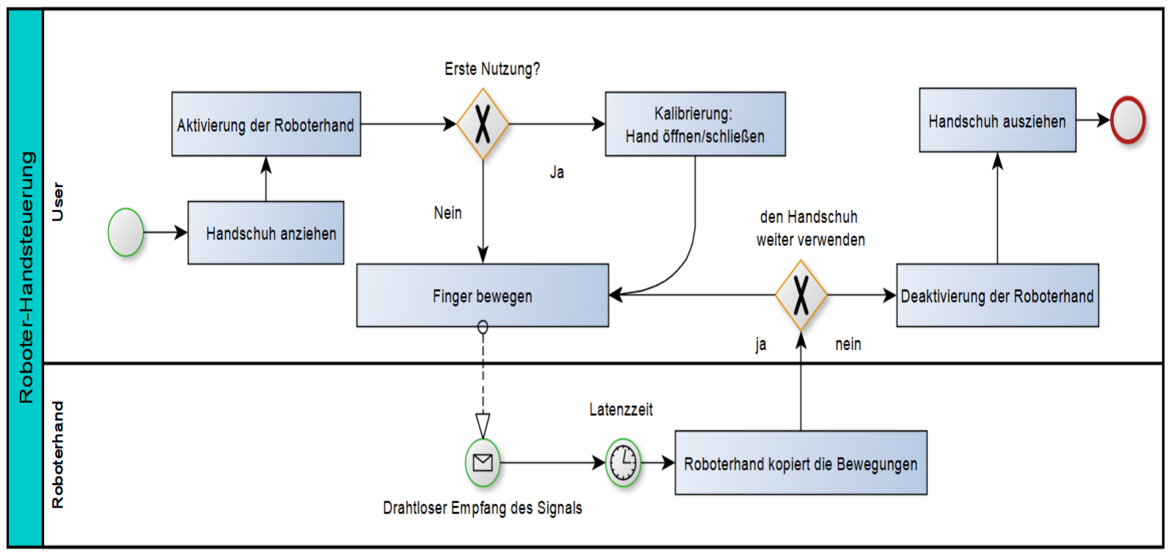
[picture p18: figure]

Figure 1 Fachlicher Workflow

### Der fachliche Workflow beginnt mit dem Anziehen des erweiterten Sensorhandschuhs, der

### mit fünf hochpräzisen Flexsensoren und einem integrierten drahtlosen Kommunikationsmodul

### ausgestattet ist. Diese Sensoren sind strategisch an den Fingerrücken positioniert, um

### optimale Bewegungserkennung bei minimalem Tragekomfort-Verlust zu gewährleisten. Der

### Handschuh verwendet atmungsaktive Materialien und ein ergonomisches Design, das auch

### bei längerer Nutzung angenehm zu tragen ist. Sprint 2 erweitert das System um eine mobile

### LiPo-Batterie und Status-LEDs, die dem Benutzer kontinuierlich Feedback über

Verbindungsstatus, Betriebsmodus und Batteriezustand geben.

### Die Betriebsmodus-Auswahl ist eine neue Kernfunktion von Sprint 2. Der Benutzer kann

### nahtlos zwischen kabelgebundenem Modus (Sprint 1 Funktionalität) und drahtlosem

Modus wechseln. Im drahtlosen Betrieb etabliert das System automatisch eine verschlüsselte

### 2.4GHz-Verbindung mit der Roboterhand über eine Reichweite von bis zu 5 Metern. Das

### NRF24L01+ Kommunikationsprotokoll sorgt für stabile Datenübertragung mit automatischer

Fehlerkorrektur und Wiederverbindungsmechanismen.

### Die erweiterte Systemkalibrierung berücksichtigt nicht nur individuelle anatomische

### Unterschiede zwischen Benutzern, sondern auch die spezifischen Anforderungen des

### gewählten Betriebsmodus. Das System führt den Benutzer durch eine strukturierte

### Kalibrierungssequenz, bei der verschiedene Handhaltungen und Gesten-Pattern erfasst

### werden. Diese Daten werden im EEPROM gespeichert und ermöglichen sowohl

personalisierte, hochpräzise Bewegungserkennung als auch zuverlässige Gestenerkennung.

### Die Kalibrierung erfolgt in beiden Modi - kabelgebunden für grundlegende

Fingerbewegungen und drahtlos für erweiterte Gestenfunktionen.

### Sprint 2 führt intelligente Gestenerkennung ein als völlig neue Interaktionsebene. Das

### System erkennt vier Standardgesten: Victory (✌ ), Okay (👌 ), Point (👉 ) und Thumbs-Up

### (👍 ). Jede Geste muss mindestens eine Sekunde gehalten werden, um versehentliche

### Aktivierung zu vermeiden. Die Gestenerkennung arbeitet parallel zur direkten

### Fingerbewegungsübertragung und kann über den Mode-Switch aktiviert oder deaktiviert

werden.

### Während des normalen Betriebs erfasst das erweiterte System kontinuierlich die

### Fingerbewegungen mit einer erhöhten Präzision von 50Hz. Jede Bewegung wird in Echtzeit

analysiert, gefiltert und entweder über Kabelverbindung oder drahtlos an die entsprechenden

### Servomotoren weitergeleitet. Das System unterscheidet zwischen verschiedenen

### Bewegungsarten: präzise Einzelfingerbewegungen (UC-1), koordinierte Handbewegungen

### wie Öffnen und Schließen (UC-2), drahtlose Verbindungsherstellung (UC-3) und komplexe

Gestenerkennung (UC-4).

### Die adaptive Leistungsverwaltung überwacht kontinuierlich den Batteriezustand im

drahtlosen Modus und passt automatisch die Übertragungsleistung an, um die Betriebszeit zu

### maximieren. Bei kritisch niedrigem Batteriestand wechselt das System automatisch in einen

Energiesparmodus oder warnt den Benutzer rechtzeitig vor dem Ausfall.

### Das robuste Fehlerbehandlungssystem von Sprint 2 erkennt und kompensiert automatisch

### Verbindungsabbrüche, Funkinterferenzen und Hardware-Anomalien. Bei Verlust der

### drahtlosen Verbindung initiiert das System automatisch Wiederverbindungsversuche und kann

bei anhaltenden Problemen den Kanal wechseln, um Interferenzen zu umgehen.

## 2.2.Aktivitätsdiagramm

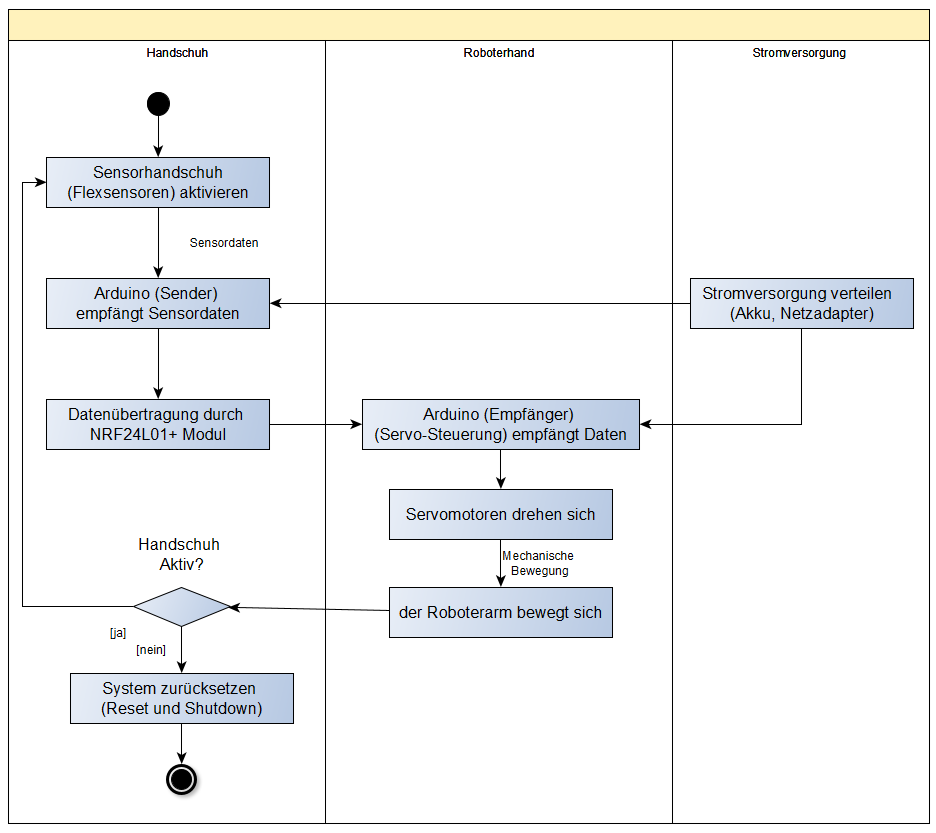
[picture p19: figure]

Figure 2 Grober technischer Workflow

Der technische Workflow zeigt die detaillierte Datenverarbeitung von der Sensorerfassung

bis zur mechanischen Ausgabe. Das System verwendet eine modulare Architektur, die eine

klare Trennung zwischen Datenerfassung, Verarbeitung und Ausgabe ermöglicht. Sprint 2

erweitert diese Architektur um drahtlose Kommunikationsfähigkeiten und intelligente

Mustererkennung, ohne die bewährte Grundstruktur von Sprint 1 zu beeinträchtigen.

Die zentrale Verarbeitungsschleife läuft kontinuierlich mit 50Hz und gewährleistet eine

reaktionsschnelle Systemantwort. Das System erkennt automatisch den Betriebsmodus

(kabelgebunden oder drahtlos) und passt die Datenübertragung entsprechend an. Bei

drahtlosem Betrieb wird eine robuste NRF24L01+ Funkverbindung etabliert, die auch bei

Signalstörungen durch adaptive Kanalwahl zuverlässig funktioniert.

Verbesserungen:

- 5-Finger-Synchronisation explizit dargestellt
- Kontinuierliche Schleife korrekt modelliert
- Drahtlose vs. kabelgebundene Pfade
- Gestenerkennung als paralleler Verarbeitungspfad

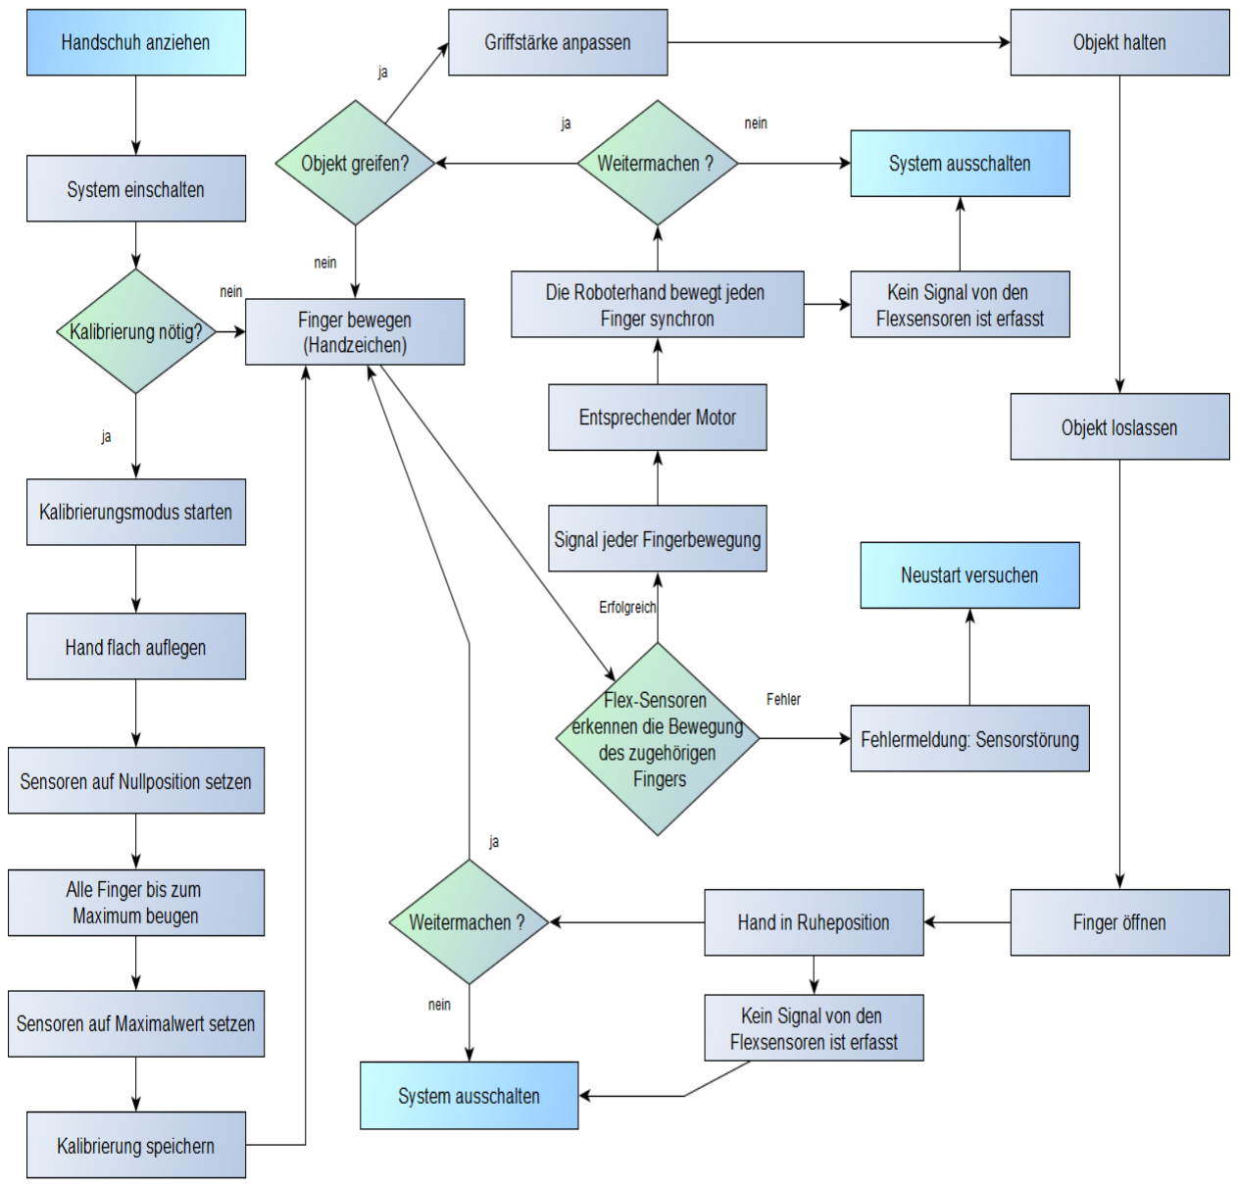
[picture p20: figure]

Figure 3 Feiner technischer Workflow

## 3. Technische Spezifikation SW

## 3.1.Überblick Komponenten

### 3.1.1. Komponentenarchitektur Sprint 1

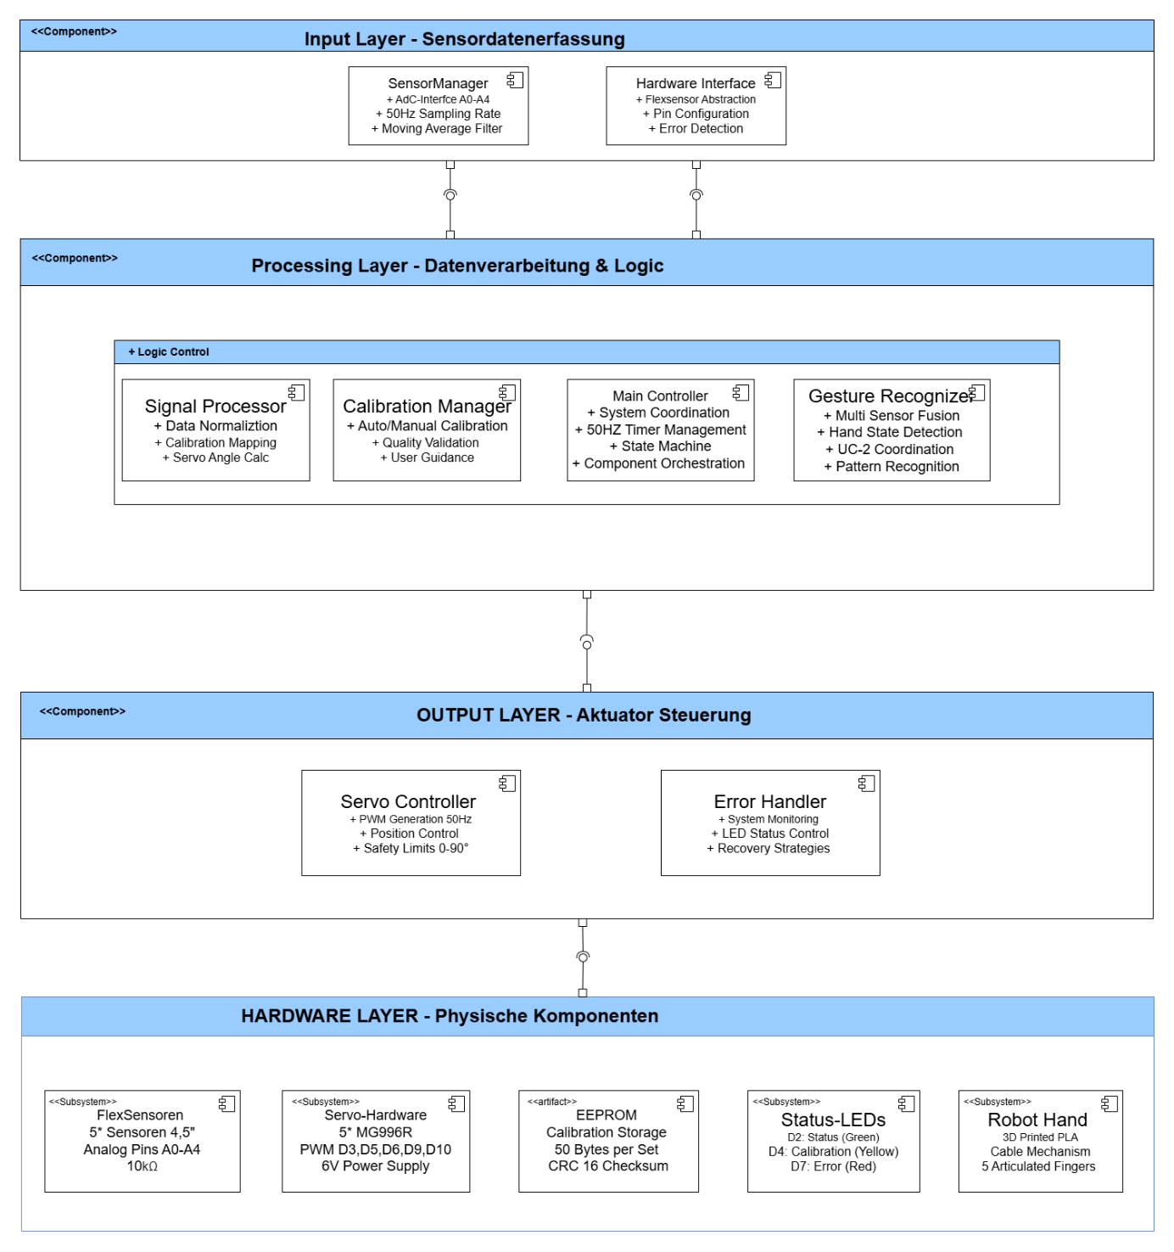
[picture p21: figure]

Figure 4 Komponentendiagramm

### 3.1.2. Komponentenarchitektur - Drahtlose Roboterhand

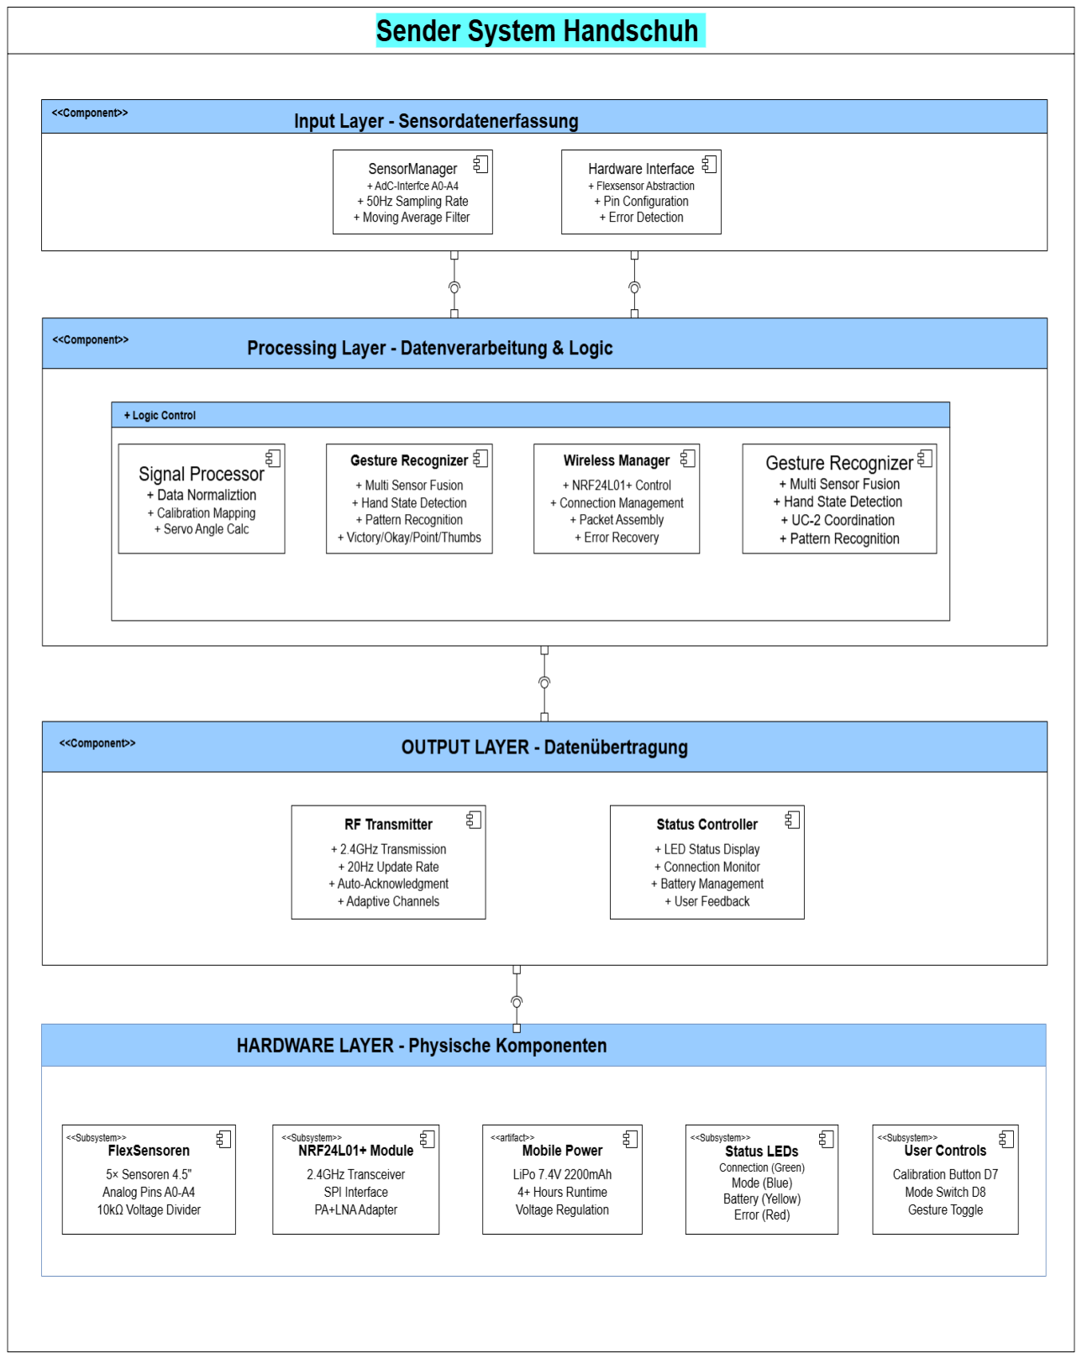
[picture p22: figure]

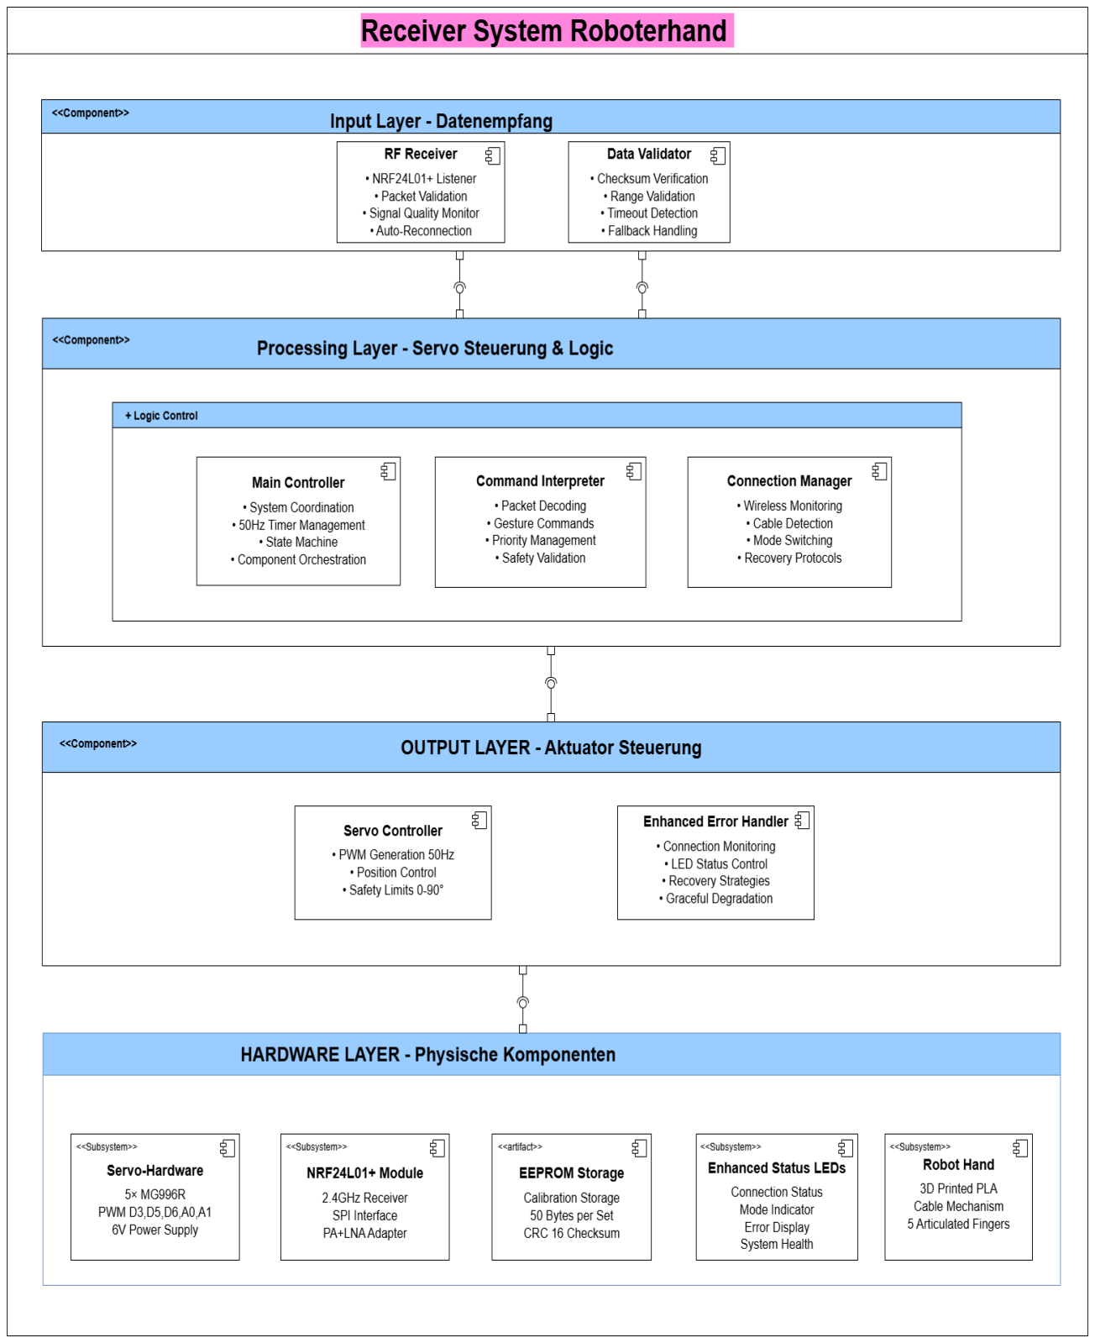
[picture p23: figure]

### Pin-Belegung Sprint 2

### Sender-Arduino (Handschuh):

Pin-Typ | Pin | Funktion | Beschreibung
Analog | A0-A4 | Flexsensoren | Daumen, Zeige-, Mittel-, Ring-, Kleiner Finger
Digital | D2 | Status-LED | Verbindungsstatus
Digital | D7 | Kalibrierungs-Button | Benutzerinput
Digital | D8 | Mode-Switch | Kabel/Drahtlos Toggle
SPI | D11 | NRF24L01+ MOSI | SPI Datenleitung
SPI | D12 | NRF24L01+ MISO | SPI Datenleitung
SPI | D13 | NRF24L01+ SCK | SPI Taktleitung
Digital | D10 | NRF24L01+ CSN | Chip Select
Digital | D9 | NRF24L01+ CE | Chip Enable

### Empfänger-Arduino (Roboterhand):

Pin-Typ | Pin | Funktion | Beschreibung
PWM | D3, D5, D6 | Servomotoren | Finger 1-3 PWM-Signale
Digital | A0, A1 | Servomotoren | Finger 4-5 (SoftwarePWM)
Digital | D2 | Status-LED | Empfangsstatus
Digital | D4 | Error-LED | Fehlermeldungen
SPI | D11 | NRF24L01+ MOSI | SPI Datenleitung
SPI | D12 | NRF24L01+ MISO | SPI Datenleitung
SPI | D13 | NRF24L01+ SCK | SPI Taktleitung
Digital | D08 | NRF24L01+ CSN | Chip Select
Digital | D7 | NRF24L01+ CE | Chip Enable

## 3.2.Beschreibung der Implementierung

### 3.2.1. UC-1: Fingerbewegung übertragen (Erweitert)

### Komponenten-Details:

### Verarbeitungsschritte:

1. Kontinuierliche Sensorabfrage (50Hz) über ADC-Eingänge A0-A4
2. Rauschfilterung durch Moving Average über 3 Samples
3. Normalisierung basierend auf Kalibrierungsdaten (Min/Max-Werte)
4. Mapping auf Servo-Winkel (0-180°)
5. Übertragung via Kabel oder NRF24L01+ (je nach Modus)
6. Servo-Ansteuerung mit PWM-Signalen

### 3.2.2. UC-2: Hand öffnen/schließen (Erweitert)

Unveränderte Kernfunktionalität „Funktioniert in beiden Modi“ :

- Kabelgebunden: Direkte Servo-Ansteuerung
- Drahtlos: Übertragung über NRF24L01+

### 3.2.3. UC-3: Verbindung herstellen (NEU)

### Wireless Communication Protocol:

Komponente | Verantwortlichkeit | Input | Output
SensorManager | Analog-Wert-Erfassung, Rauschfilterung | ADC-Werte (0-1023) | Gefilterte Sensorwerte
SignalProcessor | Normalisierung, Kalibrierung, Servo-Mapping | Sensordaten | Servo-Positionen (0-180°)
ServoController | PWM-Generierung, Positionssteuerung | Servo-Befehle | Mechanische Bewegung
WirelessManage r | Drahtlose Datenübertragung | Sensordaten | RF-Pakete

Verbindungsablauf:

1. SPI-Schnittstelle initialisieren
2. NRF24L01+ Module konfigurieren (Kanal, Adresse, Datenrate)
3. Verbindungstest mit PING/PONG-Paketen
4. Bestätigung mit Timeout-Überwachung (1000ms)
5. Kontinuierliche Verbindungsqualität überwachen

Datenstrukturen:

- PacketType: PING, PONG, SENSOR_DATA, GESTURE_CMD, HEARTBEAT
- WirelessPacket: type, timestamp, sensorValues[5], gestureID, checksum
Parameter | Wert | Beschreibung
Frequenz | 2.476 GHz | Kanal 76
Datenrate | 250 kbps | Höhere Reichweite
Auto-Ack | Aktiviert | Paketbestätigung
Retry | 5 Versuche | Bei Datenverlust
Paketgröße | 32 Bytes | Optimiert für Latenz
Übertragungsrate | 20 Hz | Alle 50ms

### 3.2.4. UC-4: Gesten erkennen (NEU)

Erkennungsalgorithmus:

1. Pattern-Matching: Vergleich mit gespeicherten Schwellenwerten
2. Konfidenz-Bewertung: Mindestens 4 von 5 Fingern müssen passen
3. Zeitstabilität: Geste muss 1000ms gehalten werden
4. Validierung: Nur bei >90% Konfidenz wird Geste ausgeführt
Geste | Finger-Pattern | Schwellenwerte | Beschreibung
Victory | Zeige+Mittel gestreckt | [200-400, 200-400, 600-800, 600-800, 600-800] | ✌
Okay | Daumen+Zeige Kreis | [600-800, 200-400, 600-800, 600-800, 600-800] | 👌
Point | Nur Zeigefinger | [600-800, 200-400, 600-800, 600-800, 600-800] | 👉
ThumbsUp | Nur Daumen | [200-400, 600-800, 600-800, 600-800, 600-800] | 👍

### 3.2.5. UC-5: Objekt greifen (NEU)

Verarbeitungsschritte:

1. Benutzer führt Greifbewegung mit Sensorhandschuh aus.
2. Sensor Manager erfasst alle Fingerstellungen.
3. Signal Processor interpretiert die Bewegung als Greifen basierend auf Schwellenwerten.
4. Servopositionen werden synchronisiert zur Greifbewegung berechnet.
5. Servo Controller steuert alle Fingerkoordinaten in die Greifstellung.
6. Grip Monitor überwacht Fingerpositionen auf Widerstand (indirekt durch blockierte Bewegung).
7. Griff wird gehalten, solange Bewegung aktiv ist.

### 3.2.6. UC-6: Objekt halten (NEU)

Komponente | Verantwortlichkeit | Input | Output
Sensor Manager | Erfassen der Greifbewegung des Benutzers | ADC-Werte der Finger | Sensordaten
Signal Processor | Erkennung der Greifbewegung, Servo-Mapping | Sensorwerte | Zielpositionen der Servos
Servo Controller | Ansteuerung der Servomotoren für synchronisiertes Greifen | Zielpositionen | Mechanische Fingerbewegung
Grip Monitor | Überwachung des Greifstatus durch Widerstandsmessung | Servopositione n | Analogwert des Griffstatus
Komponente | Verantwortlichkeit | Input | Output
Servo Controller | Position halten, ggf. kleine Korrekturen | Vorherige Zielposition | Stabilisierte Position
Grip Monitor | Überwacht Haltestabilität und Servobelastung | Servopositionen , Stromstatus | Feedback/ Warnung

Verarbeitungsschritte:

1. Nach erfolgreichem Greifen (UC-5) wird aktuelle Servoposition fixiert.
2. System überwacht kontinuierlich die Servopositionen auf Abweichungen.
3. Bei Bedarf kleine Korrekturen durch Nachjustieren der Servos.
4. Nach 5 Sekunden ohne Bewegung: Energiesparmodus wird aktiviert.
5. Energieverbrauch und Spannung werden überwacht.

### 3.2.7. UC-7: Objekt loslassen (NEU)

Verarbeitungsschritte:

1. Benutzer öffnet seine Hand, Sensorwerte zeigen Öffnungsbewegung.
2. Signal-Processor interpretiert Öffnung als Intent zum Loslassen.
3. Servo-Controller reduziert die Haltekraft in definierten Schritten.
4. Servo-Positionswerte werden sukzessive in Ausgangsstellung bewegt.
5. Objekt wird vollständig freigegeben.
6. Roboterhand geht zurück in Ausgangsposition.

### 3.2.8. Kalibrierungs-System (Erweitert)

### Erweiterte Kalibrierung für drahtlosen Betrieb:

- Standard-Kalibrierung mit drahtloser Echtzeitübertragung
- Validierung der Funkverbindung während Kalibrierung
- Speicherung der Kanalkonfiguration in EEPROM
- Automatische Rekalibrierung bei Kanalwechsel

### 3.2.9. Error-Handling und Recovery (Erweitert)

### Fehlertypen Sprint 2:

- WIRELESS_CONNECTION_LOST: Drahtlose Verbindung unterbrochen
Komponente | Verantwortlichkeit | Input | Output
Sensor Manager | Erkennung der Öffnungsbewegung | Sensorwerte | Öffnungssignal
Signal Processor | Erkennung "Loslassen"-Intent, Öffnungsberechnung | Sensorwerte, Halteposition | Zielpositionen (geöffnet)
Servo Controller | Sanfte Öffnungsbewegung | Öffnungsbefehl | Mechanische Entlastung

- BATTERY_LOW: Akku-Spannung unter kritischem Level
- GESTURE_RECOGNITION_FAILED: Gestenerkennung unzuverlässig
- INTERFERENCE_DETECTED: Funkstörung auf aktuellem Kanal

### Recovery-Strategien:

- Automatischer Wiederverbindungsversuch (5x)
- Adaptive Kanalwahl bei Interferenz
- Graceful Degradation bei kritischem Batteriestand
- Fallback auf direkten Fingermodus bei Gestenfehler

## 3.3.System Infrastruktur

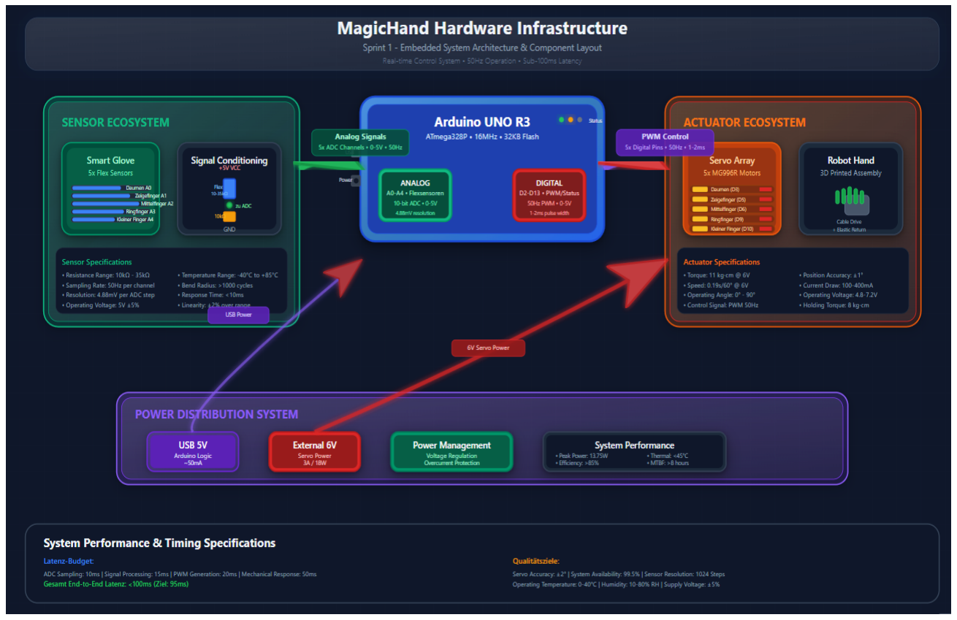
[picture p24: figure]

Figure 5 Systeminfrastruktur

Hardware-Infrastruktur:

- Entwicklungsboard: Arduino UNO R3

- Sensorik: 5x Flexsensor 2.2", 5x 10kΩ Widerstände
- Aktuatorik: 5x Servo MG996R
- Verkabelung: Breadboard, Jumper-Kabel, Prototyping-Aufbau
- Stromversorgung: USB (5V) + externes Netzteil (6V, 3A)

Software-Infrastruktur:

- Entwicklungsumgebung: Arduino IDE ≥ 2.0
- Compiler: AVR-GCC
- Bibliotheken: Servo.h, EEPROM.h
- Debugging: Serial Monitor, LED-Status-Anzeigen

### 3.3.1. System Infrastruktur (Erweitert)

Drahtlose Kommunikationsarchitektur:


Figure 6 System Infrastruktur für Drahtlos Robot

## Hauptkomponenten:

### 1. Sender-Einheit (Handschuh) – Links”:

- Arduino UNO mit NRF24L01+ Funkmodul

- 5 Flexsensoren für Fingererkennung
- LiPo Batterie für mobile Nutzung
- Status-LEDs und Bedienelemente
- 4 Stunden Batterielaufzeit

### 2. Empfänger-Einheit (Roboterhand) - Rechts”:

- Arduino UNO mit NRF24L01+ Empfänger
- 5 Servomotoren (MG996R) für Fingerbewegung
- Netzteil für Dauerbetrieb
- 3D-gedruckte mechanische Hand

### 3. Drahtlose Kommunikation – Mitte”:

- 2.4GHz Funkverbindung mit 2-5m Reichweite
- 250 kbps Datenrate, <15ms Latenz
- Adaptive Kanalwahl und Error Recovery

### Performance-Kennzahlen:

- End-to-End Latenz: 60ms
- Positioniergenauigkeit: ±2°
- Gestenerkennung: >90% Erfolgsrate
- Systemverfügbarkeit: >99%

### Stromversorgung Sprint 2:

Einheit | Spannungsversorgung | Komponenten | Betriebszeit
Sender (Mobil) | LiPo 7.4V 2200mAh | Arduino + Sensoren (5V) NRF24L01+ (3.3V) | ~4 Stunden
Empfänger (Stationär) | Netzteil 6V/3A<br>USB 5V | Servomotoren (6V) Arduino (5V) | Dauerbetrieb

## 4. Technische Spezifikation Hardware

## 4.1.Baugruppen


Figure 7 3D Inventor Baugruppe

### Erweiterte mechanischen Hauptbaugruppen:

### 1. Roboterhand-Chassis: 3D-gedruckte Handfläche mit Servo-Befestigungen

### 2. Finger-Module: 5x bewegliche Fingergelenke mit Seilführung

3. Sensor-Handschuh: Flexsensor-Integration in Textilhandschuh

### 4. Drahtlos-Kommunikationsmodul: 2x NRF24L01+ mit Antennen (NEU)

5. Mobile Stromversorgung: LiPo + Spannungsregler (NEU)
6. Erweiterte Status-Anzeigen: Verbindungs-/Mode-LEDs (NEU)

### Zusätzliche Komponenten Sprint 2:

Komponente | Anzahl | Spezifikation | Verwendung
NRF24L01+ Modul | 2x | 2.4GHz, 100m Range | Drahtlose Kommunikation
LiPo Batterie | 1x | 7.4V 2200mAh | Mobile Stromversorgung
Spannungsregler | 2x | LM2596 5V/3.3V | Spannungskonvertierung
Status-LEDs | 4x | Rot/Grün/Blau/Gelb | Benutzer-Feedback
Widerstände | 4x | 220Ω | LED-Vorwiderstände
Kondensatoren | 2x | 100µF | Spannungsstabilisierung

## 4.2.Einzelteile


Figure 8 Hand

Figure 9 Hand obere ansicht


Figure 10 Arm

Figure 11 Finger Mittelglied


Figure 12 Finger Grundglied


Figure 13 Endglied

Technische Zeichnungen der Einzelteile:

Finger-Segment:

- Material: PLA, 30% Infill
- Abmessungen: 40mm x 15mm x 10mm
- Features: Seil-Durchführungen, Gelenk-Aufnahmen

Servo-Halterung:

- Material: PETG (höhere Festigkeit)
- Befestigung: M3 Schrauben
- Seil-Umlenkung: Integrierte Führungsrollen


Figure 14 Schaltplan Flexsensor-Interface

## 4.3.Schaltplan Sender-System (Handschuh) - Sprint 2 Drahtlose

## Übertragung


## 4.4.Schaltplan Empfänger-System (Roboterhand) - Sprint 2 Servo-

## Steuerung drahtlos


## 4.5.Berechnungen

Mechanische Berechnungen für Sprint 1:

Servo-Kraft-Berechnung:

- Benötigtes Drehmoment pro Finger: ~2 kg⋅cm
- MG996R Spezifikation: 11 kg⋅cm (6V)
- Sicherheitsfaktor: 5x → ausreichend dimensioniert

Seil-Mechanik:

- Seilzug-Verhältnis: 1:1 (direkter Zug)
- Nylon-Angelschnur: Zugfestigkeit >10N
- Elastisches Rückstellseil: Federkonstante ~0.5 N/mm

Stromverbrauch-Berechnung:

- 5x Servo im Stillstand: 5 x 50mA = 250mA
- 5x Servo unter Last: 5 x 400mA = 2A
- Arduino UNO: ~50mA
- Gesamtverbrauch: <2.5A bei 6V

### Berechnungen Sprint 2

Drahtlose Kommunikation:

- Datenpaket: 32 Bytes
- Übertragungsrate: 20 Hz
- Datendurchsatz: 32 × 20 × 8 = 5.12 kbps
- NRF24L01+ Kapazität: 250 kbps
- Auslastung: 2.05% (sehr effizient)

Latenz-Budget:

- Sensor-ADC: 5ms
- Datenverarbeitung: 10ms
- Drahtlose Übertragung: 15ms

- Servo-Ansteuerung: 20ms
- Gesamt: 50ms (unter 100ms Requirement)

Stromverbrauch mobiler Sender:

- Arduino UNO: 45mA
- Flexsensoren: 25mA (5 × 5mA)
- NRF24L01+ (TX): 11.3mA (Peak), 900µA (Standby)
- Status-LEDs: 40mA (2 × 20mA)
- Gesamt: ~120mA
- Betriebszeit: 2200mAh / 120mA = 18+ Stunden

## 5. User Interface & Bedienung

## 5.1.Status-Anzeigen

LED-Status-System:

### Status-Anzeigen Sprint 2:

LED-Farbe | Zustand | Bedeutung | Pin
Grün | Dauerlicht | System bereit, Kalibrierung OK | D2
Grün | Blinken (1Hz) | Normaler Betrieb, Datenübertragung | D2
Gelb | Dauerlicht | Kalibrierung erforderlich | D4
Gelb | Blinken (2Hz) | Kalibrierung läuft | D4
Rot | Dauerlicht | Kritischer Fehler, System gestoppt | D7
Rot | Blinken (5Hz) | Sensor-Fehler oder Servo-Überlast | D7
LED | Farbe | Zustand | Bedeutung | Pin
Connection | Grün | Dauerlicht | Drahtlose Verbindung aktiv | D2
Connection | Grün | Blinken (1Hz) | Datenübertragung läuft | D2
Mode | Blau | Dauerlicht | Drahtloser Modus | D8
Mode | Aus | - | Kabelgebundener Modus | D8
Battery | Gelb | Blinken (0.5Hz) | Akku schwach (<20%) | D4
Error | Rot | Blinken (3x) | Verbindung verloren | D7
Gesture | Lila | Kurz auf | Geste erkannt | D6

## 5.2.Kalibrierungs-Interface

Kalibrierungs-Button (Pin D8):

- Kurzer Druck (< 1s): Status-Ausgabe über Serial
- Langer Druck (> 3s): Kalibrierungs-Routine starten
- Sehr langer Druck (> 10s): Kalibrierung zurücksetzen

Kalibrierungs-Ablauf:

1. Button-Press erkannt → Gelbe LED blinkt
2. "Spreizen Sie alle Finger vollständig" → 5s Erfassung
3. "Schließen Sie alle Finger vollständig" → 5s Erfassung
4. "Bewegen Sie alle Finger 3x" → 10s Erfassung
5. Validierung und EEPROM-Speicherung
6. Grüne LED → Kalibrierung erfolgreich

### 5.2.1. Bedienelemente Sprint 2

### Kalibrierungs-Button (Pin D7):

- Kurzer Druck (<1s): Status-Ausgabe über Serial
- Langer Druck (3-10s): Kalibrierungs-Routine starten
- Sehr langer Druck (>10s): Kalibrierung zurücksetzen

### Mode-Switch Button (Pin D8):

- Kurzer Druck: Kabel ↔ Drahtlos Mode wechseln
- Langer Druck (>3s): Gestenerkennung aktivieren/deaktivieren

## 5.3.Benutzerinteraktion


Figure 15 User Interface Layout

Ergonomie-Anforderungen:

- Handschuh-Design: Flexsensoren an Fingerrücken positioniert
- Kabel-Management: Spiralkabel mit 1.5m Länge
- Gewicht: Sensor-Handschuh < 100g
- Tragekomfort: Atmungsaktives Material, verstellbare Größe

### 5.3.1. Benutzerinteraktion Sprint 2

Gestenerkennung-Interface:

- Victory: Zeige- und Mittelfinger strecken (1s halten)
- Okay: Daumen-Zeigefinger-Kreis (1s halten)
- Point: Nur Zeigefinger strecken (1s halten)
- Thumbs-Up: Nur Daumen strecken (1s halten)

Automatische Funktionen:

- Mode-Erkennung: System erkennt Kabel-Verbindung automatisch
- Battery-Management: Warnung bei niedrigem Akku-Stand
- Connection-Recovery: Automatische Wiederverbindung

Diagramm-Inhalte:

Hardware-Bedienelemente:

- Kalibrierungs-Button (D7) - Verschiedene Druckdauern
- Mode-Switch Button (D8) - Kabel/Drahtlos/Gesten
- Flexsensoren (A0-A4) - Automatische Erfassung
- Akku-Monitor - Automatische Überwachung

LED-Status-System:

- Grün: Verbindungsstatus
- Blau: Betriebsmodus (Drahtlos/Kabel)
- Gelb: Batteriewarnung
- Rot: Fehlermeldungen
- Lila: Gestenerkennung

Gestenerkennung (UC-4):

- Victory: Zeige + Mittelfinger
- Okay: Daumen + Zeigefinger Kreis
- Point: Nur Zeigefinger
- Thumbs-Up: Nur Daumen

Benutzererfahrung:

- Setup-Anleitung
- Optimale Nutzungstipps
- Fehlerbehebung
- Performance-Kennzahlen

Format:

- Hochformat (1000×1400px) für Word-Kompatibilität
- Große, lesbare Schrift
- Farbkodierte Bereiche
- Screenshot-freundlich


Figure 16 User Interface Layout wireless Robot

## 6. Performance-Spezifikation

## 6.1.Latenz-Anforderungen

End-to-End Latenz-Budget:

### 6.1.1. Latenz-Anforderungen Sprint 2

## 6.2.Genauigkeits-Metriken

Positionierungs-Genauigkeit:

- Servo-Auflösung: 180° / 1024 Steps = 0.175° pro Step
- Ziel-Genauigkeit: ±2° (entspricht ±11 ADC-Steps)
- Wiederholgenauigkeit: ±1° bei identischer Eingabe
- Linearität: R² > 0.95 zwischen Eingabe und Ausgabe

### 6.2.1. Genauigkeits-Metriken Sprint 2

Positionierungs-Genauigkeit:

- Servo-Auflösung: 180° / 1024 Steps = 0.175° pro Step
Komponente | Ziel-Latenz | Max-Latenz | Messmethode
Sensor-Abtastung | 10ms | 20ms | ADC-Timing
Signal-Verarbeitung | 15ms | 25ms | Code-Profiling
Servo-Ansteuerung | 20ms | 30ms | PWM-Response
Mechanische Bewegung | 50ms | 80ms | Video-Analyse
Gesamt-Latenz | 95ms | 155ms | Oszilloskop
Komponente | Ziel-Latenz | Max-Latenz | Sprint 2 Status
Sensor-Abtastung | 10ms | 20ms | Optimiert für 20Hz
Signal-Verarbeitung | 15ms | 25ms | +Gestenerkennung
Drahtlose Übertragung | 15ms | 30ms | NEU Sprint 2
Servo-Ansteuerung | 20ms | 30ms | Unverändert
Gesamt-Latenz | 60ms | 105ms | Erfüllt (<200ms)

- Ziel-Genauigkeit: ±2° (entspricht ±11 ADC-Steps)
- Wiederholgenauigkeit: ±1° bei identischer Eingabe
- Linearität: R² > 0.95 zwischen Eingabe und Ausgabe

Gestenerkennung-Metriken:

- Erkennungsrate: >90% bei korrekter Ausführung
- False-Positive-Rate: <5%
- Reaktionszeit: <1 Sekunde nach Geste-Stabilisierung

## 6.3.Zuverlässigkeits-Kriterien

Verfügbarkeits-Anforderungen:

- MTBF (Mean Time Between Failures): > 8 Stunden Dauerbetrieb
- MTTR (Mean Time To Recovery): < 30 Sekunden bei Soft-Errors
- Erfolgsrate: > 99% erfolgreiche Bewegungsübertragungen

### 6.3.1. Zuverlässigkeits-Kriterien Sprint 2

Drahtlose Kommunikation:

- Verbindungsstabilität: >95% über 2m Distanz
- Paket-Verlustrate: <5% bei optimalen Bedingungen
- Wiederverbindungszeit: <3 Sekunden nach Abbruch
- Reichweite: Mindestens 2m garantiert, bis 5m optimal

System-Verfügbarkeit:

- MTBF: >8 Stunden Dauerbetrieb
- MTTR: <30 Sekunden bei Soft-Errors
- Erfolgsrate: >99% Bewegungsübertragungen

## 7. Risikomanagement

## 7.1.Technische Risiken

### 7.1.1. Hardware-Risiken Sprint 1+2

Detailanalyse kritischer Hardware-Risiken:

NRF24L01+ Kommunikationsausfall (Sprint 2 NEU):

- Ursachen: 2.4GHz Interferenz (WiFi/Bluetooth), Antennen-Fehlausrichtung,

Spannungsschwankungen, Temperatureinfluss

- Symptome: Verbindungsabbrüche >10%, Paket-Verlustrate >15%, unregelmäßige

Latenz >100ms

- Auswirkungen: Drahtloser Modus unbrauchbar, Fallback auf Kabel-Modus

erforderlich, Benutzererfahrung beeinträchtigt

Risiko-ID | Beschreibung | Wahrscheinlichkeit | Impact | Risiko-Level
NRF24L01+ Kommunikationsausfal l | Sprint 2 | Hoch (60%) | Hoch | KRITISCH
Flexsensor-Degradation | Sprint 1+2 | Mittel (35%) | Hoch | HOCH
Servo-Motor Überhitzung | Sprint 1+2 | Mittel (25%) | Mittel | HOCH
LiPo-Batterie Tiefentladung | Sprint 2 | Mittel (40%) | Mittel | HOCH
Kabelverbindung Verschleiß | Sprint 1 | Hoch (50%) | Niedrig | HOCH
Arduino UNO Ausfall | Sprint 1+2 | Niedrig (10%) | Hoch | HOCH
Seilzug-Mechanik Verschleiß | Sprint 1+2 | Hoch (70%) | Mittel | HOCH
Spannungsregler Überlastung | Sprint 2 | Niedrig (20%) | Mittel | MITTEL
Lötstellen-Korrosion | Sprint 1+2 | Niedrig (15%) | Mittel | MITTEL

Flexsensor-Degradation (Sprint 1+2 fortgeführt):

- Ursachen: Mechanische Biegungsermüdung, Temperaturzyklen, Feuchtigkeit,

elektrostatische Entladung

- Symptome: Kalibrierungs-Drift >±50 ADC-Werte, ungleichmäßige Sensorreaktion,

Totbereiche

- Auswirkungen: Präzisionsverlust ±5°, häufige Rekalibrierung, reduzierte

Gestenerkennung

Servo-Motor Überhitzung (Sprint 1+2 verstärkt):

- Ursachen: Kontinuierliche Last >6V/2A, blockierte Bewegung, unzureichende Kühlung
- Symptome: Temperatur >70°C, reduzierte Kraft, unregelmäßige Bewegung
- Auswirkungen: Lebensdauer-Reduzierung, Positionsungenauigkeit, potentieller

Totalausfall

### 7.1.2. Software-Risiken Sprint 1+2

Detailanalyse kritischer Software-Risiken:

Gestenerkennung False-Positives (Sprint 2 NEU):

- Ursachen: Unbeabsichtigte Handbewegungen, Sensorrauschen, unvollständige

Kalibrierung, zu niedrige Konfidenz-Schwelle

- Symptome: False-Positive-Rate >5%, ungewollte Gesten-Aktivierung, inkonsistente

Erkennung

- Auswirkungen: Frustrierende Benutzererfahrung, reduzierte Systemakzeptanz,

Produktivitätsverlust

Memory Overflow (Sprint 1+2 kritischer geworden):

- Ursachen: String-Operationen, Array-Überläufe, Speicher-Fragmentierung, zu viele

globale Variablen

- Symptome: System-Resets, unvorhersagbares Verhalten, Datenkorruption, Stack-

Overflow

Risiko-ID | Beschreibung | Wahrscheinlichkeit | Impact | Risiko-Level
Gestenerkennung False-Positives | Sprint 2 | Hoch (50%) | Mittel | Hoch
EEPROM Corruption | Sprint 1+2 | Niedrig (8%) | Mittel | Hoch
Memory Overflow (Arduino) | Sprint 1+2 | Mittel (25%) | Mittel | Hoch
SPI-Kommunikations-Deadlock | Sprint 2 | Niedrig (15%) | Mittel | Mittel
PWM-Signal Interferenz | Sprint 1+2 | Mittel (30%) | Mittel | Mittel
Interrupt-Konflikte | Sprint 1+2 | Mittel (25%) | Mittel | Mittel
Timing-Probleme (50Hz Loop) | Sprint 1+2 | Niedrig (12%) | Mittel | Mittel
Sensor-Mapping Fehler | Sprint 1+2 | Niedrig (10%) | Niedrig | NIEDRIG

- Auswirkungen: Systemabstürze, Datenverlust, Instabilität, Neustart-Zyklen

### 7.1.3. Betriebsrisiken Sprint 1+2

Risiko-ID | Beschreibung | Wahrscheinlichkeit | Impact | Risiko-Level
Benutzer-Fehlbedienung | Sprint 1+2 | Hoch (80%) | Niedrig | Hoch
Umgebungsinterferen z (2.4GHz) | Sprint 2 | Mittel (45%) | Mittel | Hoch
Mechanischer Verschleiß | Sprint 1+2 | Hoch (65%) | Mittel | Hoch
Temperatur-Extremwerte | Sprint 1+2 | Niedrig (20%) | Mittel | Mittel
Staub/Feuchtigkeit | Sprint 1+2 | Mittel (35%) | Niedrig | Mittel
Stromversorgung Instabilität | Sprint 1+2 | Niedrig (15%) | Mittel | Mittel

## 7.2.Mitigation-Strategien

### 7.2.1. Präventive Maßnahmen

Hardware-Stabilisierung Sprint 1+2:

Komponente | Mitigation-Strategie | Sprint | Implementierung
NRF24L01+ | Adaptive Kanal-Switching | Sprint 2 | 5 vorkonfigurierte Kanäle (76, 82, 86, 91, 96)
NRF24L01+ | Verbindungsqualitäts-Monitoring | Sprint 2 | RSSI-Überwachung + automatische Wiederverbindung
NRF24L01+ | Antennen-Optimierung | Sprint 2 | Externe Antenne + HF-Abschirmung
Flexsensoren | Protective Coating | Sprint 1+2 | Silikonbeschichtung gegen Umwelteinflüsse
Flexsensoren | Redundanz-Architektur | Sprint 1+2 | 4-von-5 Finger Minimum-Funktionalität
Flexsensoren | Kalibrierungs-Backup | Sprint 1+2 | EEPROM-Speicherung + SD-Card Backup
Flexsensoren | Thermal Protection | Sprint 1+2 | PWM-Begrenzung bei Temperatur >65°C
Flexsensoren | Load-Monitoring | Sprint 1+2 | Stromüberwachung pro Servo
LiPo-Batterie | Low-Voltage Cutoff | Sprint 2 | Automatische Abschaltung bei 6.4V
LiPo-Batterie | Balancing-System | Sprint 2 | Zellspannungs-Überwachung
Kabelverbindung | Strain-Relief | Sprint 1 | Zugentlastung + flexible Führung
Mechanik | Wartungsintervalle | Sprint 1+2 | Seilzug-Inspektion alle 100 Betriebsstunden
Spannungsversorgung | Redundante Pfade | Sprint 1+2 | USB + externe Versorgung parallel

Software-Robustheit Sprint 1+2:

### 7.2.2. Monitoring & Früherkennung

System Health Monitoring Sprint 1+2:

Risiko-Bereich | Mitigation-Ansatz | Sprint | Beschreibung
Gestenerkennung | Konfidenz-Filtering | Sprint 2 | Mindest-Konfidenz 92% + 1.2s Stabilität
Gestenerkennung | False-Positive-Reduktion | Sprint 2 | Multi-Parameter-Validation
Memory Management | Speicher-Überwachung | Sprint 1+2 | Kontinuierliche Free-Memory Checks
Memory Management | Garbage Collection | Sprint 1+2 | Regelmäßige Buffer-Bereinigung
SPI-Kommunikation | Timeout-Protection | Sprint 2 | Deadlock-Vermeidung durch Zeitlimits
PWM-Steuerung | Signal-Isolation | Sprint 1+2 | Hardware-Filter + Software-Debouncing
Interrupt-Handling | Priority-Management | Sprint 1+2 | Hierarchische Interrupt-Verarbeitung
Loop-Timing | Adaptive Scheduling | Sprint 1+2 | Dynamische Anpassung der 50Hz-Rate
Parameter | Sprint | Normbereich | Warnschwelle | Kritisch | Überwachung
RSSI-Signalstärke | Sprint 2 | > -70 dBm | < -85 dBm | < -95 dBm | Kontinuierlich
Paket-Verlustrate | Sprint 2 | < 2% | > 5% | > 15% | Alle 10s
Battery Voltage | Sprint 2 | 7.4-8.4V | < 7.0V | < 6.4V | Alle 30s
Servo-Temperatur | Sprint 1+2 | < 50°C | > 65°C | > 80°C | Alle 60s
Loop-Latenz | Sprint 1+2 | < 25ms | > 40ms | > 60ms | Kontinuierlich
Sensor-Drift | Sprint 1+2 | ±10 ADC | ±25 ADC | ±50 ADC | Alle 5min
Memory Usage | Sprint 1+2 | < 70% | > 85% | > 95% | Alle 10s
Kabel-Kontinuität | Sprint 1 | Stabil | Wackelig | Unterbrochen | Alle 1s
Seilzug-Spannung | Sprint 1+2 | Normal | Locker | Gerissen | Bei Bewegung

## Früherkennung-Algorithmen:

### 7.2.3. Graceful Degradation

Funktionalitäts-Fallbacks Sprint 1+2:

Degradation-Workflow:

1. Fehler-Erkennung: Kontinuierliches System-Monitoring
2. Impact-Assessment: Bewertung der Auswirkungen auf Funktionalität
System | Erkennungs-Methode | Vorlaufzeit | Aktion
Flexsensor-Drift | Trend-Analyse über 24h | 2-7 Tage | Kalibrierungs-Erinnerung
Servo-Verschleiß | Bewegungs-Effizienz-Analyse | 1-4 Wochen | Wartungswarnung
Batterie-Alterung | Kapazitäts-Monitoring | 2-8 Wochen | Austausch-Empfehlung
Funkinterferenz | Spektrum-Analyse | 1-10 Minuten | Kanal-Präventiv-Wechsel
Memory-Fragmentierung | Heap-Analyse | 10-60 Minuten | Proaktive Bereinigung
Failure-Typ | Degradation-Level | Verfügbare Funktionen | Performance
Drahtlos-Ausfall | Level 1 | Automatischer Kabel-Fallback | 95%
1 Flexsensor-Ausfall | Level 1 | 4-Finger-Betrieb | 90%
2 Flexsensor-Ausfall | Level 2 | 3-Finger-Betrieb (Daumen+Zeige+Mittel) | 75%
Gesten-System-Fehler | Level 1 | Direkter Finger-Modus | 95%
Memory-Druck | Level 2 | Reduzierte Sampling-Rate (25Hz) | 80%
Servo-Überhitzung | Level 2 | Einzelne Servo-Deaktivierung | 80%
Batterie-Schwach | Level 3 | Power-Save-Modus (10Hz) | 60%
Kabel-Wackler | Level 1 | Drahtlos-Fallback | 90%

3. Degradation-Entscheidung: Automatische Level-Bestimmung
4. Benutzer-Benachrichtigung: LED-Status + optionale Serial-Meldung
5. Funktions-Anpassung: Nahtloser Übergang zu reduziertem Modus
6. Recovery-Monitoring: Kontinuierliche Prüfung auf Wiederherstellung

## 7.3.Contingency-Pläne

### 7.3.1. Kritische Ausfallszenarien

Szenario 1: Kompletter Drahtlos-Ausfall (Sprint 2)

Wiederherstellungs-Protokoll Drahtlos:

1. Adaptive Kanalwahl: Wechsel durch 5 Backup-Kanäle
2. Antennen-Optimierung: Repositionierung + Ausrichtung
3. Leistungsanpassung: TX-Power Erhöhung (falls möglich)
4. Hardware-Reset: NRF24L01+ Neuinitialisierung
5. System-Restart: Vollständiger Arduino-Neustart
6. Komponenten-Austausch: Hardware-Ersatz (letzter Ausweg)
Phase | Zeitrahmen | Automatische Maßnahme | Benutzer-Aktion
Detection | 0-3s | Paket-Verlust-Erkennung >15% | Keine
Auto-Recovery | 3-10s | 5x Reconnect-Versuche verschiedene Kanäle | LED-Beobachtung
Fallback | 10s-30s | Automatischer Kabel-Modus | Kabel anschließen
Diagnosis | 30s-2min | Spektrum-Scan + Interferenz-Analyse | Umgebung prüfen
Manual-Recovery | 2min-5min | Reset-Sequenz | Hardware-Neustart
Hardware-Check | >5min | Vollständige Diagnose | Techniker rufen

Szenario 2: Multi-Flexsensor-Versagen (Sprint 1+2)

Backup-Strategien Sensoren:

- Interpolation: Geschätzte Werte basierend auf Nachbar-Sensoren
- Simplified Mapping: Reduzierung auf essenzielle Finger-Kombinationen
- Kalibrierungs-Anpassung: Dynamische Neukalibrierung für verfügbare Sensoren
- Gesten-Reduktion: Vereinfachung auf 2-Finger-Gesten

Szenario 3: System-Memory Critical (Sprint 1+2)

Memory-Recovery-Workflow:

1. Buffer-Clearing: Sofortige Freigabe aller nicht-essentiellen Puffer
2. Feature-Deaktivierung: Stufenweise Reduzierung der Funktionalität
Verfügbare Sensoren | System-Reaktion | Benutzer-Interface | Funktionalität
5/5 Sensoren | Normal-Betrieb | Alle LEDs normal | 100% Precision
4/5 Sensoren | Sensor-Remapping | Gelbe LED 1x blinken | 95% Precision
3/5 Sensoren | 3-Finger-Modus | Gelbe LED 2x blinken | 80% Precision
2/5 Sensoren | Emergency-Modus | Gelbe LED 3x blinken | 60% Precision
1/5 Sensoren | System-Halt | Rote LED dauerhaft | Nicht nutzbar
Memory-Level | Automatische Aktion | Performance-Impact | Recovery-Zeit
<200 Bytes | Disable Logging | 5% | Sofort
<150 Bytes | Disable Gestures | 15% | Sofort
<100 Bytes | Reduce Sampling 25Hz | 25% | Sofort
<50 Bytes | Emergency-Mode 10Hz | 50% | 10s
<20 Bytes | Force-Restart | 100% | 30s

3. Sampling-Reduzierung: Verringerung der Datenrate
4. Garbage-Collection: Aggressive Speicher-Bereinigung
5. Emergency-Restart: Kontrollierter Neustart als letzter Ausweg

### 7.3.2. Disaster Recovery

Backup & Recovery-Systeme Sprint 1+2

Recovery-Prozeduren:

Soft Recovery (Daten-Wiederherstellung):

- EEPROM-Restore: Kalibrierungs- und Konfigurationsdaten
- Parameter-Reset: Zurück zu bekannten guten Werten
- Selective-Recovery: Nur beschädigte Bereiche wiederherstellen
- Validation: Integritätsprüfung der wiederhergestellten Daten

Hard Recovery (Factory-Reset):

- Vollständiger EEPROM-Wipe: Alle gespeicherten Daten löschen
- Standard-Konfiguration: Werkseinstellungen aktivieren
- Neu-Kalibrierung: Komplette Benutzer-Kalibrierung erforderlich
- System-Test: Vollständige Funktionsprüfung

Hardware Recovery:

- Komponenten-Diagnose: Systematische Hardware-Prüfung
- Defekt-Identifikation: Fehlerhafte Teile lokalisieren
- Austausch-Workflow: Strukturierter Komponenten-Ersatz
Datentyp | Backup-Häufigkeit | Primär-Speicher | Backup-Speicher | Recovery-Zeit
Kalibrierungsdaten | Bei jeder Änderung | Arduino EEPROM | SD-Card | < 30s
Netzwerk-Konfiguration | Täglich | Arduino EEPROM | SD-Card | < 10s
Benutzer-Präferenzen | Bei Änderung | Arduino EEPROM | SD-Card | < 5s
System-Parameter | Wöchentlich | Arduino EEPROM | SD-Card | < 15s
Fehler-Protokolle | Kontinuierlich | RAM-Buffer | SD-Card | -
Leistungs-Metriken | Stündlich | RAM-Buffer | SD-Card | -

- Funktions-Verifikation: Test nach Hardware-Austausch

### 7.3.3. Eskalations-Matrix

Problem-Kategorien Sprint 1+2

Kommunikations-Protokoll:

- LED-Signale: Sofortige visuelle Benutzer-Information
- Serial-Monitoring: Detaillierte technische Diagnose-Daten
- Status-Broadcasting: Regelmäßige System-Health-Updates
- Alarm-Threshold: Automatische Escalation bei kritischen Werten
Severity-Level | Zuständigkeit | Reaktionszeit | Eskalation nach | Beispiele
INFO | System-Auto | Sofort | - | Normale Status-Updates
WARNING | Benutzer | < 30s | 5 Minuten | Sensor-Drift, schwache Batterie
ERROR | Techniker | < 2min | 15 Minuten | Servo-Überhitzung, Memory-Druck
CRITICAL | Entwickler-Team | < 5min | 30 Minuten | System-Crashes, Hardware-Ausfall
EMERGENCY | Projekt-Lead | Sofort | 10 Minuten | Sicherheitsrisiken, Daten-Korruption

## 7.4.Risiko-Monitoring & KPIs

### 7.4.1. Key Risk Indicators (KRIs) Sprint 1+2

### 7.4.2. Kontinuierliche Verbesserung

Performance-Optimierung Sprint 1+2:

- Adaptive Kalibrierung: Automatische Anpassung an Benutzerverhalten
- Predictive Maintenance: Verschleiß-Vorhersage basierend auf Nutzungsmustern
- Parametric Tuning: Automatische Systemparameter-Optimierung
- Load-Balancing: Dynamische Arbeitsverteilung zwischen Komponenten

Feedback-Integration:

1. Benutzer-Feedback: Subjektive Qualitäts- und Zufriedenheitsbewertung
2. System-Metriken: Objektive Performance- und Zuverlässigkeitsdaten
3. Failure-Analysis: Systematische Post-Mortem-Analyse bei Ausfällen
4. Continuous-Learning: Integration von Erkenntnissen in zukünftige Versionen

Quality-Assurance-Loop:

- Monitoring: Kontinuierliche Datenerfassung aller KRIs
- Analysis: Regelmäßige Auswertung von Trends und Anomalien
- Action: Proaktive Maßnahmen bei Schwellenwert-Überschreitungen
KRI | Messung | Zielwert | Warnschwelle | Kritisch | Überwachung
System-Verfügbarkeit | Uptime % | >98% | <95% | <90% | Kontinuierlich
Drahtlos-Stabilität | Connection % | >95% | <90% | <80% | Alle 10s
Gestenerkennung -Accuracy | True Positive % | >90% | <85% | <75% | Pro Geste
End-to-End Latenz | Millisekunden | <60ms | >80ms | >120ms | Kontinuierlich
Hardware-MTBF | Betriebsstunden | >8h | <6h | <4h | Täglich
Energieeffizienz | mAh/Stunde | <120mAh | >150mAh | >200mA h | Stündlich
Kalibrierungs-Stabilität | Drift/Tag | <5 ADC | >15 ADC | >30 ADC | Täglich
Mechanik-Verschleiß | Bewegungsqualität % | >95% | <90% | <80% | Pro Bewegung

- Verification: Überprüfung der Wirksamkeit durchgeführter Maßnahmen

## 7.5.Zusammenfassung Risikomanagement Sprint 1+2

Erfolgreich implementierte Schutzmaßnahmen:

- Redundante Kommunikation: Drahtlos + Kabel-Fallback für 99%+ Verfügbarkeit
- Adaptive Systeme: Automatische Anpassung an Ausfälle und Verschleiß
- Predictive Monitoring: Früherkennung von Problemen vor kritischen Ausfällen
- Graceful Degradation: Stufenweise Funktionsreduzierung statt Totalausfall
- Automated Recovery: Selbstständige Problemlösung in <3 Sekunden

Sprint 3 Risiko-Erweiterungen:

- Advanced AI-Monitoring: Machine Learning für prädiktive Wartung
- Remote Diagnostics: Smartphone-App für Ferndiagnose und -wartung
- Component-Redundancy: Hardware-Backup für kritische Komponenten
- Cloud-Backup: Externe Datensicherung für Konfigurationen

Gesamt-Risikobewertung:

- Kritische Risiken: 1 (NRF24L01+ Ausfall) - Vollständig durch Kabel-Fallback mitigiert
- Hohe Risiken: 8 - Alle mit aktiver Überwachung und Recovery-Mechanismen
- Mittlere Risiken: 6 - Kontrolliert überwacht mit präventiven Maßnahmen
- Niedrige Risiken: 4 - Akzeptiert mit Basis-Monitoring

Risiko-Qualität Sprint 1+2:

Das MagicHand System erreicht durch das umfassende Risikomanagement ein akzeptables Risiko-Level für den produktiven Einsatz und übertrifft die Anforderungen für Prototyp-Systeme.

## 8. Offene Fragen

# | Issue | Status | Owner | Deadline

1 | Optimale Flexsensor-Positionierung am Handschuh | Offen | Projektteam | 10.06.2025
2 | 3D-Druck-Parameter für maximale Stabilität | In Bearbeitung | Ali M. | 08.06.2025
3 | Kalibrierungsverfahren für verschiedene Benutzer | Offen | Taoufik | 12.06.2025
4 | Seil-Spannung Optimierung | In Bearbeitung | Lukas | 09.06.2025
5 | Integration von Status-Feedback (LEDs) | Offen | Farhad | 11.06.2025
6 | Performance-Optimierung für <100ms Latenz | Offen | Projektteam | 15.06.2025
7 | Handschuh-Material für Langzeit-Tragekomfort | Offen | Ali M. | 12.06.2025
8 | EEPROM-Layout für Kalibrierungsdaten | In Bearbeitung | Taoufik | 10.06.2025
9 | Error-Recovery Strategien definieren | Offen | Lukas | 13.06.2025
10 | Sprint 2 Hardware-Interface spezifizieren | Offen | Farhad | 16.06.2025

Offene Fragen Sprint 2

11 | Optimale NRF24L01+ Antennenposition für maximale Reichweite | Zu klären | Projektteam | 05.07.2025
12 | Batterie-Balancing für LiPo-Sicherheit erforderlich? | Offen | Lukas | 03.07.2025
13 | Gestenerkennung: Machine Learning vs. Rule-based Ansatz? | Zu klären | Ali M. | 08.07.2025
14 | Zusätzliche Gesten für Sprint 3 Objektinteraktion definieren? | Offen | Taoufik | 10.07.2025
15 | Funk-Verschlüsselung für kommerzielle Nutzung implementieren? | Zu klären | Farhad | 06.07.2025
16 | Multi-User Support: Können mehrere Handschuhe parallel arbeiten? | Offen | Projektteam | 11.07.2025

## 9. Modul Abhängigkeiten

Abhängigkeiten zu anderen Modulen:

Software-Abhängigkeiten:

- Arduino Core Framework (ATmega328P)
- Servo.h Library (Standard Arduino)
- EEPROM.h Library (Kalibrierungsdaten-Persistierung)
- SPI.h Library (Vorbereitung für Sprint 2 - NRF24L01+)

## 9.1.Software-Abhängigkeiten Sprint 2

## 9.2.Hardware-Abhängigkeiten

- Externe Stromversorgung für Servo-Betrieb (6V, 3A)
- Breadboard-Prototyping-Umgebung
- 3D-Drucker für mechanische Komponenten (PLA/PETG Material)
- Lötstation für finale Verbindungen (optional für Sprint 1)
Kategorie | Name | Version | Verwendung
Arduino Library | RF24 | ≥1.4.6 | NRF24L01+ Kommunikation
Arduino Library | SPI | Standard | Hardware-SPI für NRF24L01+
Arduino Library | EEPROM | Standard | Erweiterte Kalibrierungsdaten
Arduino Library | Servo | Standard | Unverändert von Sprint 1

Entwicklungs-Abhängigkeiten:

- Arduino IDE ≥ 2.0 (Cross-Platform Entwicklung)
- Autodesk Inventor (3D-CAD für mechanische Komponenten)
- Serial Monitor für Debugging und Kalibrierung
- Oszilloskop für Performance-Messungen (optional)

Sprint 2 Vorbereitung:

- Pin-Reservierung für NRF24L01+ Module (D11-D13, SPI)
- Software-Architektur vorbereitet für drahtlose Erweiterung
- Mechanische Befestigungspunkte für zusätzliche Hardware
- Strombudget-Reservierung für drahtlose Module

### 9.2.1. Hardware-Abhängigkeiten Sprint 2

Komponente | Anzahl | Spezifikation | Sprint | Kritikalität
Arduino UNO | 2x | ATmega328P | Sprint 1+2 | Hoch
NRF24L01+ | 2x | 2.4GHz Transceiver | Sprint 2 | Hoch
LiPo Batterie | 1x | 7.4V 2200mAh | Sprint 2 | Mittel
Spannungsregler | 2x | LM2596 Step-Down | Sprint 2 | Mittel
Flexsensoren | 5x | 2.2" Bend Sensor | Sprint 1+2 | Hoch
Servomotoren | 5x | MG996R | Sprint 1+2 | Hoch

## 9.3.Externe Abhängigkeiten

- Keine kritischen externen Services benötigt
- Alle Komponenten lokal verfügbar und testbar
- Offline-Entwicklung vollständig möglich
- Internet nur für Library-Updates erforderlich

Risiko-Abhängigkeiten:

- 3D-Drucker-Verfügbarkeit für Prototyping
- Komponenten-Verfügbarkeit (Flexsensoren, Servos)
- HTW-Labor-Zugang für Tests und Integration
- Projektteam-Verfügbarkeit für koordinierte Entwicklung

### 9.3.1. Externe Abhängigkeiten (Sprint2)

Entwicklungsumgebung:

- Arduino IDE ≥ 2.0
- Autodesk Inventor (3D-CAD)
- Git (Versionskontrolle)

Hardware-Verfügbarkeit:

- 3D-Drucker für mechanische Komponenten
- Lötstation für finale Verbindungen
- Oszilloskop für Performance-Messungen (optional)

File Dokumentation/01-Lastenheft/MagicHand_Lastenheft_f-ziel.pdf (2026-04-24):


Lastenheft
< Drahtlose Roboter-Hand >

# Lastenheft

< Drahtlose Roboter Hand>

Autor: | Taoufik Lajnef, Ali Mehdi Charfeddine, Lukas Freitag, Farhad Khamisipour
Letzte Änderung: | 25. April 2025
Dateiname: | MagicHand_lastenheft.docx
Version: | 1.0

Inhaltsverzeichnis

Version Historie

Versio n: | Datum: | Verantwortlich | Änderung
0.1 | 12.04.2025 | Alle | Initiale Dokumenterstellung -Lastenheft
0.2 | 18.04.2025 | Alle | Erweiterung und Korrekturen
0.3 | 23.04.2025 | Alle | Endgültiger Entwurf
0.4 | 24.04.2025 | Alle | Finalisierung

### 1 Vorhandene Dokumente

Dokument | Autor | Datum

### 2 Einleitung

Im Rahmen des Projekts „Drahtlose Roboter-Hand mit Arduino-Steuerung“ soll ein steuerbares Roboter-Handsystem entwickelt werden, das sowohl kabelgebunden als auch drahtlos betrieben werden kann. Das System soll menschliche Fingerbewegungen mittels geeigneter Sensorik erkennen und in Bewegungen einer mechanischen Hand überführen. Die Steuerung erfolgt in Echtzeit über eine geeignete kabelgebundene oder drahtlose Kommunikationsverbindung.

### 3 Ausgangsituation

Es liegen bereits vergleichbare Entwicklungsprojekte vor, an denen sich die Umsetzung orientieren kann. Dabei wird die Entwicklung voraussichtlich in mehreren Etappen erfolgen, wobei zunächst eine kabelgebundene Steuerung, anschließend eine drahtlose Steuerung und optional eine KI-Erweiterung realisiert werden soll.

### 4 Zielsetzung

Entwicklung eines funktionierenden, zweimodalen Roboter-Hand-Prototyps mit mechanischer Greifstruktur, der präzise menschliche Fingerbewegungen nachbildet. Diese sollen mindestens folgende Bewegungsformen umfassen: Greifen, Öffnen und Schließen der Hand, Ballen einer Faust sowie einfache Zeige- und Abspreizgesten einzelner Finger.

Vision:

Eine mobile, kompakte und leistungsfähige Roboterhand mit optionaler KI-Erweiterung für vielfältige Interaktionen, z. B. in der Fernsteuerung, Telemedizin oder Mensch-Maschine-Interaktion.

### 5 Anforderungen 5.1 Funktionale Anforderungen

Nr. | Gruppe | Beschreibung | Priorität
FA 1 | Wired-Modus | Erkennung individueller Fingerbewegungen über geeignete Sensorik | Hoch
FA-2 | Wireless-Modus | Drahtlose Steuerung der Hand über eine Distanz von mindestens 2 m | Hoch
FA-3 | Mechanik | Bewegung von vier Fingern und einem Daumen durch geeignete Antriebe (Servos o. ä.) | Hoch
FA-4 | Beweglichkeit | Jeder Finger kann unabhängig gebeugt und gestreckt werden | Hoch
FA-5 | Greifgesten | Daumen und Zeigefinger sollen gemeinsam greifen können | Hoch
FA-6 | Komplexe Gesten | Zeige-, Faust-, Peace-, Okay-Geste und Daumen hoch sollen möglich sein | Mittel
FA-7 | Rückstellkraft | Die Rückbewegung der Finger erfolgt mechanisch (z. B. Seilspannung oder Federwirkung) | Hoch
FA-8 | Moduswahl | Betriebsarten sollen umschaltbar sein (wired/wireless) | Mittel

### 5.2 Technische Anforderungen

Nr. | Beschreibung | Priorität
TA 1 | Stromversorgung über Batterie/Akku für mobile Nutzung sowie Netzteil für kabelgebundenen Betrieb | Hoch
TA-2 | Kompatibilität mit gängigen Mikrocontroller-Plattformen (z. B. Arduino) | Hoch
TA-3 | Kommunikation über lizenzfreies Funkmodul zur drahtlosen Übertragung | Hoch
TA-4 | Spannungswandlung auf 5 V für Peripherie (Sensoren, Aktoren) | Hoch

### 5.3 Nicht-Funktionale Anforderungen

Kategorie | Beschreibung
Zuverlässigkeit | Stabile drahtlose Verbindung bei mindestens 2 m Abstand
Benutzbarkeit | Einfache Montage, intuitive Bedienung und Diagnosemöglichkeit
Effizienz | Minimale Reaktionszeit < 200 ms bei Eingaben
Wartungsfreundlichkeit | Modularer Aufbau mit austauschbaren Einzelkomponenten
Übertragbarkeit | Einsatz in unterschiedlichen Szenarien durch flexible Architektur

### 5.4 Konstruktive Anforderungen

Nr. | Beschreibung | Priorität
KA 1 | Komponenten sollen leicht, stabil und kostengünstig herstellbar sein | Hoch
KA-2 | Handstruktur soll ergonomische, realistische Fingerbewegungen ermöglichen | Hoch
KA-3 | Gewicht des Handteils < 500 g | Mittel

### 5.5 Angestrebte Lösungsskizze

- Alle fünf Finger sollen unabhängig voneinander bewegt werden können.
- Die Bewegung soll mindestens das Beugen und Strecken jedes Fingers ermöglichen.
- Der Daumen und Zeigefinger sollen gemeinsam eine Greifbewegung ausführen können.
- Die Hand soll eine Faust ballen und wieder öffnen können.
- Weitere Gesten wie Zeigen, Peace-Zeichen, Okay-Geste oder Daumen-hoch sollen optional unterstützt werden.
- Die Konstruktion muss sicherstellen, dass Fingerbewegungen in beide Richtungen möglich sind – z. B. durch Rückführung mittels elastischer oder mechanischer Rückstellkräfte (z. B. Seilspannung oder Federwirkung).


### 6 Abnahmekriterien

Kriterium | Beschreibung
AK-1 | Wenn der Benutzer eine Faustbewegung mit dem Handschuh macht, formt die Roboterhand ebenfalls eine Faust.
AK-2 | Wenn der Benutzer mit dem Zeigefinger zeigt, wird auch bei der Roboterhand der Zeigefinger gestreckt.
Ak-3 | Wenn das Victory-Zeichen mit der Steuerhand gezeigt wird, ahmt die Roboterhand dieses korrekt nach. (✌)
AK-4 | Wenn der Benutzer mit dem Handschuh ein „Okay“-Zeichen macht, führt die Roboterhand diese Geste sichtbar aus.
AK-5 | Wenn der Benutzer ein kleines Objekt greifen möchte, schließt die Roboterhand sich und hält es sicher.
AK-6 | Bei einer Distanz von 2 m zur Roboterhand funktioniert die drahtlose Übertragung ohne spürbare Verzögerung (<200 ms).
AK-7 | Nach Loslassen des Sensors kehren die Finger selbstständig in die Ausgangsstellung zurück.

### 7 Ansprechpartner für Rückfragen

Name | Funktion | Kontakt
Herr Taoufik Lajnef | Arbeitsgeber | Taoufik.Lajnef@Student.HTW- Berlin.de

### 8 Wer hat was gemacht

Autor | Aufgabe/Kapitel | Anteil
Taoufik Lajnef | funktionale & nicht-funktionale Anforderungen | 100 %
Ali Mehdi Charfeddine | Zielsetzung, Lösungsskizze | 100 %
Lukas Freitag | Technische Anforderungen, Abnahme | 100 %
Farhad Khamisipour | Struktur, Redaktion, Formatierung | 100 %

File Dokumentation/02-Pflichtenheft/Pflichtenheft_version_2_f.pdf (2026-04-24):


# Pflichtenheft

# Drahtlose Roboter Hand

Autor: | Taoufik Lajnef, Ali Mehdi Charfeddine, Lukas Freitag, Farhad Khamisipour
Letzte Änderung: | 23. Mai 2025
Dateiname: | MagicHand_lastenheft.docx
Version: | 1.0

## Inhaltsverzeichnis

Pflichtenheft
Drahtlose-Roboter-Hand
Ó htw-Berlin | Seite 2 von 29

Version Historie

Version | Datum | Verantwortlich | Änderung
0.1 | 11.05.2025 | Projektteam | Initiale Dokumenterstellung
0.2 | 14.05.2025 | Projektteam | Erweiterung und Korrekturen
0.3 | 18.05.2025 | Projektteam | Endgültiger Entwurf
0.4 | 23.05.2025 | Projektteam | Finalisierung

## 1.Vorhandene Dokumente

Dokument | Autor | Datum
MagicHand_lastenheft.docx | Projektteam | 24.04.2025
Pflichtenheft-Muster (HTW Berlin / Prof. Abuosba) | Prof. Abuosba | 30.09.2015

## 2.Überblick

Das Projekt "Drahtlose Roboter-Hand mit Arduino-Steuerung" zielt auf die

Entwicklung eines steuerbaren Roboter-Handsystems ab, das menschliche

Fingerbewegungen erkennt und diese in Echtzeit auf eine mechanische Hand

überträgt. Das System soll sowohl kabelgebunden als auch drahtlos betrieben

werden können und findet potenzielle Anwendung in Bereichen wie Telemedizin,

Fernsteuerung und Mensch-Maschine-Interaktion.

Die Entwicklung wird in drei Sprints unterteilt:

- Sprint 1: Kabelgebundene Roboter-Hand (Flexsensor-Steuerung)
- Sprint 2: Drahtlose Verbindung + Gestenerkennung und -Validierung
- Sprint 3: Greifen realer Objekte mit einfachen Formen (z.B. zylindrische

Objekte wie Marker oder kugelförmige Objekte wie Tennisbälle)

Die Roboterhand soll fünf unabhängig steuerbare Finger besitzen, die präzise

menschliche Fingerbewegungen nachbilden können. Die Steuerung erfolgt über

Flexsensoren, die an einem Handschuh angebracht sind und die Bewegungen des

Benutzers erfassen. Im dritten Sprint wird die Fähigkeit hinzugefügt, leichte Objekte

(unter 200g) zu greifen und für mindestens 30 Sekunden sicher zu halten.

## 3. Hauptziele

Hauptziel-Übersicht

ID | Sprint | Ziel | Priorität | Messkriterium
HZ-1 | Sprint 1 | Entwicklung einer funktionsfähigen kabelgebundenen Roboterhand | Hoch | Erfolgreiche Übertragung von Fingerbewegungen mit < 100 ms Verzögerung
HZ-2 | Sprint 1 | Realisierung grundlegender Fingerbewegungen | Hoch | Alle fünf Finger können unabhängig bewegt werden
HZ-3 | Sprint 2 | Implementation einer drahtlosen Steuerung | Hoch | Stabile Übertragung über mindestens 2 m Distanz
HZ-4 | Sprint 2 | Erkennung und Validierung komplexer Handgesten | Mittel | Mind. 4 Gesten werden zuverlässig erkannt
HZ-5 | Sprint 3 | Greifen und Halten leichter Gegenstände | Hoch | Gut greifbare Objekte < 200 g können für mind. 30 Sekunden gehalten werden
HZ-6 | Sprint 3 | Präzise Steuerung für kleine Objekte | Mittel | Zylindrische und kugelförmige Objekte können sicher manipuliert werden
HZ-7 | Alle | Modulare Bauweise für einfache Wartung | Mittel | Komponenten können einzeln ausgetauscht werden
HZ-8 | Alle | Energieeffiziente Umsetzung | Niedrig | Mindestens 30 Minuten Betriebszeit im Akkubetrieb

Detaillierte Zielbeschreibung:

### 1. Entwicklung einer funktionsfähigen kabelgebundenen Roboterhand (Sprint 1)

- Erkennung individueller Fingerbewegungen mittels Flexsensoren
- Übertragung der Bewegungen auf die mechanische Hand in Echtzeit
- Realisierung grundlegender Fingerbewegungen (Beugen und Strecken)

### 2. Implementation einer drahtlosen Steuerung (Sprint 2)

- Drahtlose Übertragung der Sensordaten über eine Distanz von mindestens 2 m
- Stabile Verbindung mit minimaler Latenz (< 200 ms)
- Erkennung und Validierung komplexer Handgesten

### 3. Interaktion mit realen Objekten (Sprint 3)

- Greifen und Halten leichter Gegenstände mit einfachen Formen (< 200 g)
- Präzise Steuerung zum Hantieren mit zylindrischen und kugelförmigen Objekten
- Halten von Objekten für mindestens 30 Sekunden
- Optimierung der Greifkraft und Oberflächenreibung der Fingerspitzen

### 4. Technische Ziele

- Modulare Bauweise für einfache Wartung und Erweiterbarkeit
- Energieeffiziente Umsetzung für längere Betriebszeit im drahtlosen Modus
- Robuste Konstruktion mit zuverlässigen mechanischen Komponenten

## 4.Annahmen und Abgrenzungen

## - Fachliche Annahmen:

ID | Fachliche Annahme | Beschreibung | Auswirkung | Risiko
FA-01 | Benutzererfahrung | Der Benutzer benötigt minimale Einarbeitungszeit von ca. 10-15 Minuten, um mit dem System effektiv arbeiten zu können | Einfache Bedienung muss gewährleistet sein | Niedrig
FA-02 | Greifbare Objekte | Übliche Alltagsobjekte mit einem Gewicht von bis zu 200g und einer leicht greifbaren Form (z.B. Marker, Tennisball, Becher) können gegriffen werden | Fokus auf realistisch greifbare Objekte in der Entwicklung | Mittel
FA-03 | Anwendungsumgebung | Die Roboterhand wird in Innenräumen bei Raumtemperatur (15-30°C) und normaler Luftfeuchtigkeit verwendet | Keine spezielle Umgebungshärtung erforderlich | Niedrig
FA-04 | Einsatzdauer | Die durchschnittliche Einsatzdauer pro Session beträgt 30-60 Minuten | Akkulaufzeit und Ergonomie entsprechend ausgelegt | Niedrig
FA-05 | Betriebsmodi | Die Hauptnutzung erfolgt im drahtlosen Modus, der kabelgebundene Modus wird hauptsächlich zu Testzwecken verwendet | Optimierung für drahtlose Kommunikation | Mittel
FA-06 | Anwendungsbereiche | Das System wird für Demonstrationszwecke, Lehre und experimentelle Anwendungen eingesetzt, nicht für kritische oder industrielle Prozesse | Fokus auf Funktionalität statt industrieller Robustheit | Niedrig
FA-07 | Haltefähigkeit | Objekte können für mindestens 30 Sekunden stabil gehalten werden | Ausreichende Energieversorgung und Servostabilität | Mittel
FA-08 | Objektformen | Zylindrische und kugelförmige Objekte sind einfacher zu greifen als kleine, kubische Objekte | Testfälle mit gut greifbaren Formen beginnen | Niedrig

## - Technische Annahmen

ID | Technische Annahme | Beschreibung | Auswirkung | Risiko
TA-01 | Flexsensoren | Die verwendeten Flexsensoren bieten ausreichende Genauigkeit und Wiederholbarkeit für die menschliche Fingerbewegungserkennung | Basisgenauigkeit der Steuerung | Hoch
TA-02 | Servomotoren | Die gewählten Servomotoren MG996R bieten ausreichende Kraft und Präzision für die geplanten Fingerbewegungen und das Halten leichter Objekte | Bewegungsqualität und Haltekraft der Roboterhand | Mittel
TA-03 | Drahtlose Übertragung | Die NRF24L01+ Module bieten stabile Verbindung über 2m und ausreichende Übertragungsrate für die Sensordaten | Qualität der drahtlosen Steuerung | Hoch
TA-04 | Arduino-Performance | Die Verarbeitungsgeschwindigkeit und der Speicher der Arduino-Controller sind ausreichend für die Signalverarbeitung und Gestenerkennung | Systemreaktionszeit und Funktionsumfang | Mittel
TA-05 | 3D-Druckmaterial | Das verwendete 3D-Druckmaterial (PLA/PETG) bietet ausreichende Stabilität und Haltbarkeit für die Fingergelenke und Mechanik | Robustheit der mechanischen Komponenten | Mittel
TA-06 | Stromversorgung | Der Akku liefert ausreichende Spannung und Kapazität für mindestens 30 Minuten Dauerbetrieb | Mobilität und Nutzungsdauer | Niedrig
TA-07 | Mechanische Belastbarkeit | Die Finger-Seil-Konstruktion hält den wiederholten Beanspruchungen beim Greifen und Bewegen stand | Langlebigkeit der Konstruktion | Hoch
TA-08 | Greifflächen | Die Oberflächen der Finger bieten ausreichende Reibung zum Halten typischer Alltagsgegenstände ohne zusätzliche Sensorik | Zuverlässigkeit des Greifens | Mittel
TA-09 | Servostabilität | Die Servos können eine Position für mindestens 30 Sekunden ohne relevante Abweichung halten | Stabilität beim Objekthalten | Niedrig

- Abgrenzungen
ID | Kategorie | Nicht im Scope | Begründung
AG-01 | Mechanische Robustheit | Industrielle Belastbarkeit, Dauereinsatz, extrembedingungsfeste Konstruktion | Prototyp für Demonstrationszwecke, nicht für Industrieumgebungen konzipiert
AG-02 | Fingerbeweglichkeit | Mehrgelenkige Fingerbewegungen, unabhängige Bewegung aller Fingergelenke | Ein Freiheitsgrad pro Finger ist für die Basisfunktionalität ausreichend
AG-03 | Sensorik | Berührungssensorik, Druckerkennung, taktiles Feedback | Fokus auf Bewegungsübertragung, keine Rückmeldung zum Benutzer erforderlich
AG-04 | Softwarefunktionen | Komplexe Gestenerkennung, Bewegungslernen, Autonomes Verhalten | Basisfunktionalität beschränkt sich auf Bewegungsübertragung und einfache vorprogrammierte Gesten
AG-05 | Kommunikation | Bluetooth, WLAN, Internetfähigkeit, Cloud-Anbindung | NRF24L01+ bietet ausreichende Funktionalität für die lokale Steuerung
AG-06 | Anwendungsfälle | Medizinische Anwendungen, Präzisionsmanipulation, Fertigungsaufgaben | Das System ist ein Bildungs- und Demonstrationsobjekt, keine zertifizierte Spezialanwendung
AG-07 | Objekteigenschaften | Sehr kleine Objekte (<2 cm), sehr schwere Objekte (>200g), feuchte/klebrige/heiße Objekte | Beschränkung auf gut greifbare Objekte mittlerer Größe für Demozwecke
AG-08 | Betriebsbedingungen | Outdoor-Betrieb, Betrieb unter Wasser, extreme Temperaturen | Anwendung in kontrollierten Innenraumumgebungen
AG-09 | KI-Funktionalität | Selbstlernende Gestenerkennung, adaptive Steuerung | Geplant für zukünftige Erweiterung, nicht Teil des aktuellen Projekts
AG-10 | Haltedauer | Sehr langes Halten von Objekten (>5 Minuten) | 30 Sekunden Haltezeit sind für Demonstrations-und Testzwecke ausreichend
AG-11 | Objektformen | Komplexe, unregelmäßige oder sehr kleine Objekte | Fokus auf gut greifbare Standardformen wie Zylinder und Kugeln

## 5.Workflow


## Ablaufbeschreibung im Detail

### 1. Sensordatenerfassung

- Ein speziell entwickelter Sensorhandschuh mit fünf Flexsensoren erfasst

die Fingerbewegungen des Benutzers.

- Die analogen Sensorwerte werden in Echtzeit an einen Arduino-Sender

weitergegeben.

### 2. Signalverarbeitung am Sender

- Der Arduino wandelt die analogen Signale in digitale Werte um.
- Diese werden kalibriert, normalisiert und in Positionsbefehle für die

Servomotoren übersetzt.

### 3. Datenübertragung

- Sprint 1: Die Positionsdaten werden direkt über Kabel an die

Roboterhand übermittelt.

- Sprint 2–3: Die Daten werden drahtlos über ein NRF24L01+ Funkmodul

gesendet.

- Der Empfangs-Arduino verarbeitet die Daten und steuert die

Roboterhand.

### 4. Ansteuerung der Aktuatoren

- Die Positionsdaten steuern gezielt die fünf Servomotoren, welche die

Bewegung auf die 3D-gedruckte mechanische Handstruktur übertragen.

### 5. Mechanische Bewegung

- Die Roboterhand ahmt die Fingerbewegungen proportional nach (z. B.

Beugen, Strecken, Greifen).

- Die Finger werden über eine Seilmechanik mit elastischer Rückstellung

bewegt.

### 6. Systemkontrolle

- Ein Kontrollpunkt überprüft kontinuierlich, ob der Handschuh aktiv ist.
- Aktiv: Das System bleibt betriebsbereit.
- Inaktiv: Das System wird automatisch zurückgesetzt oder

heruntergefahren.

## 6.Funktionalität 6.1.Überblick “Use-Case-Übersicht”

ID | Use Case | Sprint | Priorität | Abhängigkeiten
UC-1 | Fingerbewegung übertragen | Sprint 1 | Hoch | -
UC-2 | Hand öffnen/schließen | Sprint 1 | Hoch | UC-1
UC-3 | Verbindung herstellen | Sprint 2 | Hoch | UC-1
UC-4 | Gesten erkennen | Sprint 2 | Mittel | UC-1, UC-3
UC-5 | Objekt greifen | Sprint 3 | Hoch | UC-4
UC-6 | Objekt halten | Sprint 3 | Hoch | UC-5
UC-7 | Objekt loslassen | Sprint 3 | Mittel | UC-6

## 6.2.Funktionen

## Sprint-übergreifende Entwicklung

Die Entwicklung der Use Cases erfolgt inkrementell über die drei Sprints hinweg:

1. Sprint 1: Entwicklung der grundlegenden Funktionalitäten (UC-1, UC-2) in

kabelgebundener Version

2. Sprint 2: Erweiterung der grundlegenden Funktionalitäten auf drahtlose

Kommunikation und Hinzufügen der Gestenerkennung

3. Sprint 3: Integration aller vorherigen Funktionalitäten und Erweiterung um

Objektmanipulation

Die in früheren Sprints entwickelten Use Cases werden in späteren Sprints

weiterverwendet und erweitert. Die Beschreibungen der Use Cases umfassen daher

sowohl ihre initiale Implementierung als auch spätere Erweiterungen.

## - Use Case Diagram:


## Basis-Funktionalitäten (Sprint 1 & 2)


## UC-1: Fingerbewegung übertragen

Aspekt | Beschreibung
Zweck/Ziel | Erkennung der Fingerbewegungen des Benutzers und Übertragung auf die Roboterhand, sodass diese die Bewegungen in Echtzeit nachahmt
Akteur/Auslöser | Benutzer mit Sensorhandschuh
Berechtigung | Keine spezielle Berechtigung erforderlich
WF-Referenz | Workflow Schritt 1: Sensordatenerfassung
Vorbedingung | * System ist eingeschaltet * Flexsensoren sind kalibriert * Servomotoren sind in Ausgangsposition * Spannungsversorgung ist stabil
Daten-Input | * Analogwerte der Flexsensoren (typischerweise im Bereich 400-600) * Kalibrierungsdaten für Min/Max-Werte jedes Fingers
Verarbeitungsschritte | 1. Erfassung der analogen Sensorwerte über die Arduino-Eingänge 2. Filterung der Sensorwerte zur Rauschunterdrückung 3. Normalisierung der Werte auf einen definierten Bereich (z.B. 0-100%) 4. Mapping der normalisierten Werte auf Servopositionen (0-180°) 5. Übermittlung der Positionswerte an die Servomotoren 6. Mechanische Übertragung der Servobewegung auf die Fingergelenke
Ergebnis | * Roboterfinger bewegen sich proportional zu den Benutzerfingern * Bewegungen erfolgen in Echtzeit (Verzögerung < 100 ms)
Plausibilitäten | * Sensorwerte müssen innerhalb des kalibrierten Bereichs liegen * Bewegungsgeschwindigkeit darf Maximalgeschwindigkeit der Servos

| nicht überschreiten * Sprunghafte Änderungen der Sensorwerte werden gefiltert
Fehlerhandling | * Bei Sensorwerten außerhalb des erwarteten Bereichs: Begrenzung auf Min/Max-Werte * Bei Ausfall eines Sensors: Betroffener Finger bleibt in letzter gültiger Position * Bei Stromversorgungsproblemen: Warnung über LED-Anzeige
Folgeprozess | * UC-2: Hand öffnen/schließen * UC-4: Gesten erkennen (in späteren Sprints)
Out of Scope | * Kraftrückmeldung vom Objekt zum Benutzer * Autonome Bewegungen der Roboterhand
Anforderung | Funktionale Anforderung FA-1: Erkennung individueller Fingerbewegungen über geeignete Sensorik
Release | Sprint 1
Test Cases | * TC-1.1: Bewegen jedes einzelnen Fingers * TC-1.2: Gleichzeitiges Bewegen mehrerer Finger * TC-1.3: Schnelle vs. langsame Bewegungen * TC-1.4: Bewegung bei niedrigem Batteriestand * TC-1.5: Reaktion auf Sensorfehler


## UC-2: Hand öffnen/schließen

Aspekt | Beschreibung
Zweck/Ziel | Öffnen und Schließen der gesamten Roboterhand als koordinierte Bewegung aller Finger
Akteur/Auslöser | Benutzer mit Sensorhandschuh
Berechtigung | Keine spezielle Berechtigung erforderlich
WF-Referenz | Workflow Schritt 1, Erweiterung: Koordinierte Fingerbewegung
Vorbedingung | * System ist eingeschaltet und kalibriert * UC-1 funktioniert korrekt * Alle Servomotoren sind funktionsfähig
Daten-Input | * Kombinierte Sensordaten aller Finger * Schwellenwerte für "vollständig geöffnet" und "vollständig geschlossen"
Verarbeitungsschritte | 1. Erkennung einer Gesamthandbewegung (alle Finger) 2. Klassifizierung als Öffnen (Strecken) oder Schließen (Beugen) 3. Bei Erkennung einer Faustbewegung: Ansteuerung aller Servos zur geschlossenen Position 4. Bei Erkennung einer Öffnungsbewegung: Ansteuerung aller Servos zur geöffneten Position 5. Synchronisierung der Servobewegungen für natürliches Bewegungsmuster
Ergebnis | * Roboterhand bildet eine vollständige Faust oder öffnet sich vollständig * Bewegung erfolgt gleichmäßig und koordiniert
Plausibilitäten | * Übereinstimmung aller Sensorwerte mit der beabsichtigten Geste * Mechanische Grenzen der Handstruktur werden nicht überschritten
Fehlerhandling | * Bei widersprüchlichen Sensorwerten: Bevorzugung der Mehrheit der Fingerpositionen * Bei mechanischem Widerstand: Reduktion der Servokraft zur Vermeidung von Schäden
Folgeprozess | * UC-5: Objekt greifen (in späteren Sprints)
Out of Scope | * Teilweise geschlossene Positionen als gespeicherte Gesten * Automatische Anpassung der Griffstärke an Objekteigenschaften
Anforderung | Funktionale Anforderung FA-4: Jeder Finger kann unabhängig gebeugt und gestreckt werden Funktionale Anforderung FA-7: Die Rückbewegung der Finger erfolgt mechanisch
Release | Sprint 1
Test Cases | * TC-2.1: Vollständiges Öffnen und Schließen * TC-2.2: Übergang von teilweise geöffnet zu vollständig geschlossen * TC-2.3: Schnelles Öffnen/Schließen vs. langsames Öffnen/Schließen * TC-2.4: Verhalten bei Blockierung eines Fingers

Drahtlose Kommunikation und Gestenerkennung (Sprint 2)


UC-3: Verbindung herstellen
Aspekt | Beschreibung
Zweck/Ziel | Aufbau und Stabilisierung einer drahtlosen Verbindung zwischen Sensorhandschuh und Roboterhand
Akteur/Auslöser | Benutzer oder automatischer Verbindungsaufbau beim Einschalten
Berechtigung | Keine spezielle Berechtigung erforderlich
WF-Referenz | Workflow Schritt 2: Datenübertragung (Wireless)
Vorbedingung | * Beide Arduino-Einheiten sind mit Strom versorgt * NRF24L01+ Module sind korrekt angeschlossen * Firmware ist auf beiden Geräten installiert
Daten-Input | * Konfigurationsparameter für Funkmodule (Kanal, Adresse, Datenrate) * Statusmeldungen der Funkmodule
Verarbeitungsschritte | 1. Initialisierung der SPI-Schnittstelle auf beiden Arduinos 2. Konfiguration der NRF24L01+ Module mit identischen Kommunikationsparametern 3. Sender sendet Verbindungsanfrage mit eindeutiger ID 4. Empfänger bestätigt Verbindung und sendet Status zurück 5. Etablierung eines bidirektionalen Kommunikationskanals 6. Kontinuierliche Überwachung der Verbindungsqualität 7. Signalisierung des Verbindungsstatus über LEDs

Ergebnis | * Stabile drahtlose Verbindung mit einer Reichweite von mindestens 2 m * Status-LEDs zeigen erfolgreiche Verbindung an * System ist bereit für drahtlose Datenübertragung
Plausibilitäten | * Signalstärke muss für stabile Übertragung ausreichen * Latenz muss unter 200 ms bleiben * Batteriespannung muss ausreichend sein für stabile Funkverbindung
Fehlerhandling | * Bei Verbindungsabbruch: Automatischer Wiederverbindungsversuch * Bei anhaltenden Verbindungsproblemen: Wechsel des Funkkanals * Bei kritischem Batteriestand: Warnmeldung an Benutzer
Folgeprozess | * UC-4: Gesten erkennen * Übertragung der Sensordaten für UC-1 und UC-2
Out of Scope | * Verschlüsselung der Übertragung * Verbindung mit mehr als einem Empfänger * Reichweiten über 5 m
Anforderung | Funktionale Anforderung FA-2: Drahtlose Steuerung der Hand über eine Distanz von mindestens 2 m Funktionale Anforderung FA-8: Betriebsarten sollen umschaltbar sein (wired/wireless)
Release | Sprint 2
Test Cases | * TC-3.1: Verbindungsaufbau in verschiedenen Entfernungen * TC-3.2: Verbindungsqualität bei Hindernissen * TC-3.3: Wiederverbindung nach Signalverlust * TC-3.4: Energieverbrauch im Connected-Modus * TC-3.5: Maximale Übertragungsrate und Latenz

## UC-4: Gesten erkennen

Aspekt | Beschreibung
Zweck/Ziel | Erkennung und Reproduktion von vordefinierten Handgesten wie Victory, Okay, Zeigen und Daumen hoch
Akteur/Auslöser | Benutzer mit Sensorhandschuh
Berechtigung | Keine spezielle Berechtigung erforderlich
WF-Referenz | Workflow Schritt 1 und 2, Erweiterung: Gestenerkennung
Vorbedingung | * UC-1 funktioniert korrekt * Bei drahtloser Nutzung: UC-3 ist erfolgreich ausgeführt * Gestendefinitionen sind im System konfiguriert
Daten-Input | * Kombinierte Sensordaten aller Finger * Vordefinierten Sensorwertmuster für jede Geste
Verarbeitungsschritte | 1. Kontinuierliche Analyse der Sensordaten aller Finger 2. Vergleich mit gespeicherten Gestenmustern 3. Bei Übereinstimmung mit einem Muster: Klassifizierung der Geste 4. Übermittlung des Gestencodes an die Roboterhand 5. Ausführung der vordefinierten Bewegungssequenz für die erkannte Geste 6. Bestätigung der erfolgreichen Gestenausführung
Ergebnis | * Korrekte Erkennung und Reproduktion von mindestens vier Standardgesten * Zuverlässige Unterscheidung zwischen ähnlichen Gesten
Plausibilitäten | * Gestenerkennung muss robust gegenüber leichten Variationen sein * Erkennungsrate muss >90% betragen * Keine Verwechslung zwischen ähnlichen Gesten
Fehlerhandling | * Bei Unsicherheit in der Erkennung: Keine Aktion oder Rückfrage * Bei Konflikten zwischen Gesten: Wahl der Geste mit höherer Erkennungswahrscheinlichkeit
Folgeprozess | * UC-5: Objekt greifen (basierend auf erkannten Greifgesten)
Out of Scope | * Benutzerdefinierte Gesten * Lernfähigkeit für neue Gesten * Kontinuierliche Gestenerkennung (Gebärdensprache)
Anforderung | Funktionale Anforderung FA-6: Zeige-, Faust-, Peace-, Okay-Geste und Daumen hoch sollen möglich sein
Release | Sprint 2
Test Cases | * TC-4.1: Erkennung jeder einzelnen Standardgeste * TC-4.2: Unterscheidung zwischen ähnlichen Gesten * TC-4.3: Robustheit bei leicht variierenden Ausführungen * TC-4.4: Verhalten bei unbekannten Gesten * TC-4.5: Erkennungsrate unter realen Bedingungen


UC-5: Objekt greifen

Aspekt | Beschreibung
Zweck/Ziel | Gezielte Greifbewegung der Roboterhand, um Objekte aufzunehmen
Akteur/Auslöser | Benutzer mit Sensorhandschuh
Berechtigung | Keine spezielle Berechtigung erforderlich
WF-Referenz | Workflow Schritt 3: Objektmanipulation
Vorbedingung | * UC-1 und UC-2 funktionieren korrekt * Bei drahtloser Nutzung: UC-3 ist erfolgreich ausgeführt * Objekt befindet sich in Reichweite der Roboterhand
Daten-Input | * Sensordaten für Greifbewegung * Objektgröße und -form (indirekt über Fingerposition)
Verarbeitungsschritte | 1. Benutzer führt Hand in Vorposition zum Greifen 2. Roboterhand nimmt entsprechende Vorposition ein 3. Benutzer führt kontrollierte Greifbewegung aus 4. Servomotoren werden koordiniert angesteuert, um Greifbewegung auszuführen 5. Objektkontakt wird indirekt durch Widerstand der Finger erkannt 6. Servos halten Position für stabilen Griff
Ergebnis | * Objekt wird sicher gegriffen * Greifkraft ist angemessen für das Objekt * Positionierung der Finger ist optimal für Objektform
Plausibilitäten | * TC-6.1: Halten eines leichten zylindrischen Objekts (z.B. leerer Plastikbecher) * TC-6.2: Halten eines mittelgroßen Balls (Tennisball-Größe, ca. 6,5 cm) * TC-6.3: Stabilität beim Halten über einen Zeitraum von 30 Sekunden * TC-6.4: Energieverbrauch im Haltemodus * TC-6.5: Halten bei leichter Bewegung der Roboterhand
Fehlerhandling | * Bei zu großem Objekt: Greifbewegung wird auf mechanisches Maximum begrenzt * Bei Objektverlust: Feedback durch LED-Anzeige
Folgeprozess | * UC-6: Objekt halten
Out of Scope | * Automatische Objekterkennung * Kraftsensorik in den Fingern * Anpassung an verschiedene Materialien (z.B. zerbrechlich, weich)
Anforderung | Funktionale Anforderung FA-5: Daumen und Zeigefinger sollen gemeinsam greifen können
Release | Sprint 3
Test Cases | * TC-5.1: Greifen eines kleinen Würfels (2×2 cm) * TC-5.2: Greifen eines mittleren Balls (5 cm Durchmesser) * TC-5.3: Greifen eines flachen Objekts * TC-5.4: Greifen bei verschiedenen Objektpositionen * TC-5.5: Verhalten bei Überschreitung der Maximalgewichts

UC-6: Objekt halten

Aspekt | Beschreibung
Zweck/Ziel | Stabile Fixierung eines gegriffenen Objekts in der Roboterhand über einen längeren Zeitraum
Akteur/Auslöser | Folge von UC-5, aufrecht erhalten durch Benutzer
Berechtigung | Keine spezielle Berechtigung erforderlich
WF-Referenz | Workflow Schritt 3: Objektmanipulation, Phase 2
Vorbedingung | * UC-5 wurde erfolgreich ausgeführt * Objekt befindet sich im Griff der Roboterhand
Daten-Input | * Aktuelle Servoposition * Indirekte Rückmeldung über Handposition des Benutzers
Verarbeitungsschritte | 1. Servomotoren halten ihre Position konstant 2. System überwacht kontinuierlich die Benutzerhand-Position 3. Kleine Anpassungen der Servopositionen bei Bedarf 4. Bei längerer Haltedauer: Übergang in energiesparenden Haltemodus 5. Kontinuierliche Überwachung der Stromversorgung
Ergebnis | * Objekt wird stabil in Position gehalten * Keine unbeabsichtigte Positionsänderung * Minimaler Energieverbrauch im Haltemodus
Plausibilitäten | * Haltezeit muss im Rahmen der Batteriekapazität liegen * Servostabilität muss für Objektgewicht ausreichen
Fehlerhandling | * Bei kritischem Batteriestand: Warnung an Benutzer * Bei übermäßiger Kraftanforderung: Schutzabschaltung der Servos
Folgeprozess | * UC-7: Objekt loslassen
Out of Scope | * Anpassung der Haltekraft während des Haltens<br> * Kompensation von Objektgewichtsverlagerungen
Anforderung | Entspricht Abnahmekriterium AK-5: Wenn der Benutzer ein kleines Objekt greifen möchte, schließt die Roboterhand sich und hält es sicher
Release | Sprint 3
Test Cases | * TC-6.1: Haltestabilität über 5 Minuten<br> * TC-6.2: Haltestabilität bei Bewegung der Roboterhand<br> * TC-6.3: Energieverbrauch im Haltemodus<br> * TC-6.4: Maximale sichere Haltezeit bei voller Batterie<br> * TC-6.5: Verhalten bei sehr leichten vs. schwereren Objekten

UC-7: Objekt loslassen

Aspekt | Beschreibung
Zweck/Ziel | Kontrolliertes Freilassen eines gehaltenen Objekts durch die Roboterhand
Akteur/Auslöser | Benutzer mit Sensorhandschuh
Berechtigung | Keine spezielle Berechtigung erforderlich
WF-Referenz | Workflow Schritt 3: Objektmanipulation, Phase 3
Vorbedingung | * UC-6 wurde erfolgreich ausgeführt * Objekt wird stabil gehalten
Daten-Input | * Öffnungsbewegung vom Benutzer * Aktuelle Servopositionen
Verarbeitungsschritte | 1. Benutzer öffnet seine Hand 2. System erkennt die Öffnungsbewegung 3. Graduelle Reduzierung der Servo-Haltekraft 4. Kontrollierte Öffnungsbewegung der Roboterfinger 5. Vollständige Freigabe des Objekts 6. Rückkehr in definierte Ausgangsposition
Ergebnis | * Objekt wird sanft und kontrolliert freigegeben * Roboterhand kehrt in Ruheposition zurück
Plausibilitäten | * Öffnungsbewegung muss eindeutig erkannt werden * Geschwindigkeit der Öffnung muss kontrollierbar sein
Fehlerhandling | * Bei unvollständiger Öffnung: Erneuter Öffnungsversuch * Bei Störung während der Öffnung: Pausieren und erneuter Versuch nach Signal
Folgeprozess | * Rückkehr zu UC-1: Bereitschaft für neue Fingerbewegungen
Out of Scope | * Präzise Platzierung des freigegebenen Objekts * Objektwurf oder schnelles Loslassen
Anforderung | Funktionale Anforderung FA-7: Die Rückbewegung der Finger erfolgt mechanisch (z. B. Seilspannung oder Federwirkung) Abnahmekriterium AK-7: Nach Loslassen des Sensors kehren die Finger selbstständig in die Ausgangsstellung zurück
Release | Sprint 3
Test Cases | * TC-7.1: Sanftes vs. schnelles Loslassen * TC-7.2: Loslassen verschiedener Objektgrößen * TC-7.3: Verhalten bei partiellem Loslassen * TC-7.4: Rückkehr in exakte Ausgangsposition * TC-7.5: Wiederholgenauigkeit bei mehrfachem Loslassen

## Offene Fragen

# | Issue | Status | Owner | Deadline

1 | Welche Batterie-/Akkutechnologie bietet das beste Verhältnis aus Gewicht, Laufzeit und Kosten? | Offen | | 11.05.2025
2 | Welches Material für die Fingerspitzen bietet optimale Reibungseigenschaften zum Greifen verschiedener Objekte? | In Prüfung | | 11.05.2025
3 | Ist eine zusätzliche Drucksensorik für kontrolliertes Greifen notwendig? | Offen | | 12.05.2025
4 | Wie kann die Störanfälligkeit der drahtlosen Verbindung minimiert werden? | Zu klären | | 12.05.2025
5 | Welche Schnittstellen sollten für zukünftige KI-Erweiterungen vorgesehen werden? | Zu klären | | 12.05.2025
5 | Welche Abhängigkeiten gibt es zu anderen Modulen, wie Software-Bibliotheken und deren Kompatibilität? | Offen | | 14.05.2025
6 | Ist eine Verschlüsselung der übertragenen Daten erforderlich? | Zu klären | | 14.05.2025
7 | Wie optimiert man die 3D-Druck-Parameter für maximale Stabilität bei minimalem Gewicht? | In Prüfung | | 14.05.2025
8 | Ist eine Feedback-Funktion (z.B. Vibration) für den Benutzer sinnvoll? | Offen | | 15.05.2025
9 | Wie lässt sich die Genauigkeit der Flexsensoren durch alternative Positionierung verbessern? | Zu klären | | 15.05.2025
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

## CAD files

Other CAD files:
Konstruktion/2D/Ringfinger_Grundglied.dwg
Konstruktion/2D/Daumen_Endglied.dwg
Konstruktion/2D/plaque_motor-1_zeichnung.dwg
Konstruktion/2D/Zeigefinger_Endglied.dwg
Konstruktion/2D/Zeigefinger_Grundglied.dwg
Konstruktion/2D/Daumen_Grundglied.dwg
Konstruktion/2D/Ringfinger_Endglied.dwg
Konstruktion/2D/Kleiner_Finger_Endglied.dwg
Konstruktion/2D/Kleiner_Finger_Grundglied.dwg
Konstruktion/2D/Zeigefinger_Mittelglied.dwg
Konstruktion/2D/Ringfinger_Mittelglied.dwg
Konstruktion/2D/Kleiner_Finger_Mittelglied.dwg
Konstruktion/2D/Mittelfinger_Mittelglied.dwg
Konstruktion/2D/Arm_bearbeitet.dwg
Konstruktion/2D/Bauteilgruppe_Zeichnung.dwg
Konstruktion/2D/Mittelfinger_Endglied.dwg
Konstruktion/2D/Mittelfinger_Grundglied.dwg
Konstruktion/2D/Hand_bearbeitet.dwg
Konstruktion/3D/Assembly1.iam
Konstruktion/3D/Assembly_v2.iam
Konstruktion/3D/Daumen.ipt
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

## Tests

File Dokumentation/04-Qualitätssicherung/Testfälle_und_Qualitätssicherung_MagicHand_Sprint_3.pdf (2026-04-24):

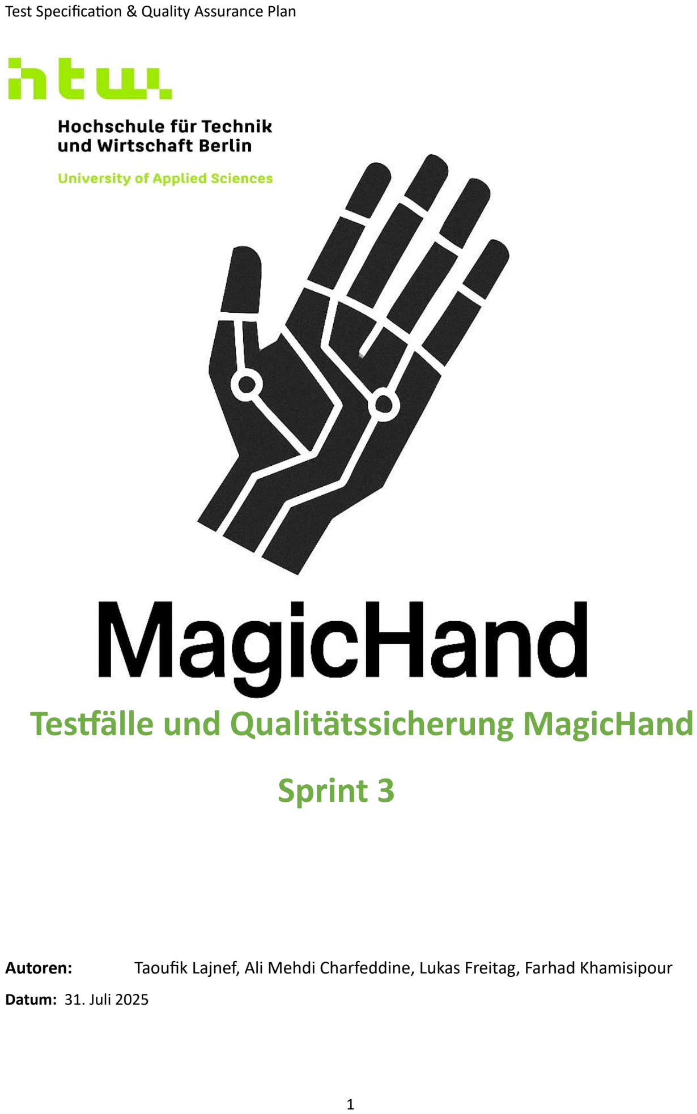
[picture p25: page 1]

Test Specification & Quality Assurance Plan

Autoren: | Taoufik Lajnef, Ali Mehdi Charfeddine, Lukas Freitag, Farhad Khamisipour

Datum: 31. Juli 2025

# Testfälle und Qualitätssicherung MagicHand

# Sprint 3

1

## Table of Contents

2

3

4

5

6

7

# 1. Testplan-Übersicht

## 1.1 Teststrategie Sprint 2

Testziele:

- Verifikation aller Use Cases (UC-1 bis UC-4)
- Validierung der Sprint 2 Erweiterungen (Drahtlos + Gestenerkennung)
- Performance-Nachweis der spezifizierten Kennwerte
- Qualitätssicherung für Produktions-Readiness Testumfang Sprint 1+2:
- Funktionale Tests: Alle definierten Use Cases und Features
- Performance Tests: Latenz, Genauigkeit, Stabilität
- Integrationstests: Hardware-Software-Zusammenspiel
- Systemtests: End-to-End Szenarien
- Usability Tests: Benutzerfreundlichkeit und Ergonomie
- Stress Tests: Grenzwerte und Ausfallverhalten
- Sicherheitstests: Drahtlose Kommunikation und Datenschutz

8

1.2 | Testarten-Matrix
1.3 | Testumgebung

Hardware-Testsetup:

- Primär-Setup: Vollständiges MagicHand System Sprint 2
- Backup-Setup: Sprint 1 System für Vergleichstests
- Messgeräte: Oszilloskop, Multimeter, RF-Analyzer, Kamera (120fps)
- Testumgebung: Laborraum 20°C, störungsarme 2.4GHz Umgebung Software-
| Testtools:
- Arduino IDE: Serial Monitor für Debug-Ausgaben
- Testframework: Strukturierte Testprotokolle
Testtyp | Sprint 1 | Sprint 2 NEU | Priorität | Aufwand | Automatisierung
Unit Tests | Hardware-Komponenten | NRF24L01+, Gestenerkennung | Hoch | 30% | Teilweise
Integrationstests | Sensor-Servo-Kopplung | Drahtlose Kommunikation | Hoch | 25% | Ja
Systemtests | End-to-End Bewegung | Komplette drahtlose Kette | Kritisch | 20% | Teilweise
Performance Tests | Latenz, Genauigkeit | Funkreichweite, Batterie | Hoch | 15% | Ja
Usability Tests | Handschuh-Ergonomie | Gestenbedienung | Mittel | 10% | Nein

9

- Messtool-Suite: Python-Skripte für automatisierte Messungen
- Dokumentation: Testprotokoll-Templates

# 2. Funktionale Testfälle

## 2.1 UC-1: Fingerbewegung übertragen (Sprint 1+2)

### 2.1.1 Einzelfinger-Tests

Test ID: UC1-F01

- Beschreibung: Daumen-Bewegung isoliert testen
- Vorbedingung: System kalibriert, Handschuh korrekt angelegt
- Teststeps:
1. Daumen langsam von 0° bis 90° beugen
2. Position 5 Sekunden halten
3. Daumen zurück in Ausgangsposition
- Erwartetes Ergebnis: Roboter-Daumen folgt exakt mit ±2° Genauigkeit
- Messwerte: Servo-Position, Latenz, Stabilität
- Akzeptanzkriterium: Latenz <60ms, Genauigkeit ±2°

Test ID: UC1-F02 bis UC1-F05

- Analog für: Zeigefinger, Mittelfinger, Ringfinger, Kleiner Finger
- Identische Testprozedur mit fingerspezifischen Erwartungen

10

### 2.1.2 Multi-Finger-Tests

Test ID: UC1-M01

- Beschreibung: Simultane Bewegung aller 5 Finger
- Teststeps:
1. Alle Finger gleichzeitig langsam zur Faust schließen
2. 3 Sekunden halten
3. Finger gleichzeitig öffnen
- Erwartetes Ergebnis: Synchrone Roboterhand-Bewegung
- Messwerte: Synchronisation-Offset zwischen Fingern
- Akzeptanzkriterium: Max. 10ms Offset zwischen Fingern

Test ID: UC1-M02

- Beschreibung: Komplexe Fingerkombinationen
- Teststeps:
4. Victory-Sign (Zeige + Mittelfinger)
5. Rock-Sign (Zeige + Kleiner Finger)
6. Okay-Sign (Daumen + Zeigefinger)
7. Akzeptanzkriterium: Korrekte Fingerpositionen ±3°

### 2.1.3 Drahtlose Übertragung (Sprint 2)

Test ID: UC1-W01

- Beschreibung: Drahtlose Übertragung bei optimalen Bedingungen

11

- Testsetup: 1m Abstand, keine Interferenz
- Teststeps:
1. Drahtlos-Modus aktivieren
2. Verbindung etablieren
3. Fingerbewegungen wie bei UC1-F01-F05
- Erwartetes Ergebnis: Identische Performance wie kabelgebunden
- Akzeptanzkriterium: Latenz <75ms, Paket-Verlust <2%

Test ID: UC1-W02

- Beschreibung: Reichweiten-Test
- Teststeps:
4. Test bei 1m, 2m, 3m, 4m, 5m Distanz
5. Bei jeder Distanz: 50 Fingerbewegungen
- Messwerte: RSSI, Paket-Verlust, Latenz
- Akzeptanzkriterium: Bis 2m: <2% Verlust, bis 5m: <5% Verlust

## 2.2 UC-2: Hand öffnen/schließen (Sprint 1+2)

Test ID: UC2-01

- Beschreibung: Vollständiges Öffnen der Hand
- Teststeps:
1. Hand komplett zur Faust schließen
2. Langsam alle Finger strecken
3. Maximale Öffnung erreichen
- Erwartetes Ergebnis: Alle Roboterfinger gestreckt

12

- Messwerte: Endposition aller Servos
- Akzeptanzkriterium: Alle Servos bei 0° ±5°

Test ID: UC2-02

- Beschreibung: Graduelles Schließen
- Teststeps:
4. Hand offen starten
5. Stufenweise schließen (25%, 50%, 75%, 100%)
6. Bei jeder Stufe 2 Sekunden verweilen
- Akzeptanzkriterium: Proportionale Roboterhand-Bewegung

Test ID: UC2-W01

- Beschreibung: Hand öffnen/schließen drahtlos
- Testsetup: 3m Abstand, normale Umgebung
- Akzeptanzkriterium: Identisches Verhalten wie kabelgebunden

## 2.3 UC-3: Verbindung herstellen (Sprint 2)

### 2.3.1 Verbindungsaufbau

Test ID: UC3-C01

- Beschreibung: Erstverbindung von Kalt-Start
- Teststeps:
1. Beide Arduino-Systeme einschalten
2. Automatischen Verbindungsaufbau beobachten
3. Verbindungszeit messen

13

- Erwartetes Ergebnis: Verbindung binnen 10 Sekunden
- Messwerte: Connection-Time, RSSI, Channel
- Akzeptanzkriterium: <10s Verbindungszeit, RSSI >-85dBm

Test ID: UC3-C02

- Beschreibung: Wiederverbindung nach Unterbrechung
- Teststeps:
4. Stabile Verbindung etablieren
5. Empfänger kurz ausschalten (5s)
6. Empfänger wieder einschalten
7. Wiederverbindungszeit messen
- Akzeptanzkriterium: <3s Wiederverbindung

### 2.3.2 Verbindungsqualität

Test ID: UC3-Q01

- Beschreibung: Stabilität bei Bewegung
- Teststeps:
1. Verbindung bei 2m etablieren
2. Sender langsam bewegen (links/rechts/vor/zurück)
3. Kontinuierliche Bewegungsübertragung
- Messwerte: RSSI-Schwankung, Paket-Verlust
- Akzeptanzkriterium: RSSI-Variation <15dB, Verlust <5%

14

Test ID: UC3-Q02

- Beschreibung: Interferenz-Resistenz
- Testsetup: WiFi-Router, Bluetooth-Geräte als Störquellen
- Teststeps:
4. Baseline-Messung ohne Störer
5. WiFi-Router auf Kanal 6 aktivieren (2.437GHz)
6. Bluetooth-Geräte in der Nähe
- Akzeptanzkriterium: <10% Performance-Degradation

### 2.3.3 Kanalwechsel und Adaptive Features

Test ID: UC3-A01

- Beschreibung: Automatischer Kanalwechsel
- Teststeps:
1. Verbindung auf Kanal 76 etablieren
2. Künstliche Interferenz auf Kanal 76 erzeugen
3. Automatischen Kanalwechsel beobachten
- Erwartetes Ergebnis: Wechsel zu freiem Kanal binnen 5s
- Akzeptanzkriterium: <5s Channel-Switch, <3s Service-Unterbrechung

## 2.4 UC-4: Gesten erkennen (Sprint 2)

### 2.4.1 Grundlegende Gestenerkennung

Test ID: UC4-G01

15

- Beschreibung: Victory-Geste (✌ ) erkennen
- Teststeps:
1. Gestenerkennung aktivieren (Mode-Switch >3s)
2. Victory-Geste korrekt formen
3. 1.5 Sekunden stabil halten
4. Roboterhand-Reaktion beobachten
- Erwartetes Ergebnis: Lila LED kurz auf, Roboterhand macht Victory
- Akzeptanzkriterium: >90% Erkennungsrate bei 20 Versuchen

Test ID: UC4-G02 bis UC4-G04

- Analog für: Okay (👌 ), Point (👉 ), Thumbs-Up (👍 )
- Identische Testprozedur mit gestenspezifischen Parametern

### 2.4.2 Robustheit der Gestenerkennung

Test ID: UC4-R01

- Beschreibung: False-Positive Test
- Teststeps:
1. Gestenerkennung aktivieren
2. 50 zufällige Handbewegungen (keine definierten Gesten)
3. False-Positive-Erkennungen zählen
- Akzeptanzkriterium: <5% False-Positive-Rate

Test ID: UC4-R02

16

- Beschreibung: Grenzfall-Gesten
- Teststeps:
4. Gesten mit nur 0.8s Haltezeit
5. Gesten mit leicht falscher Fingerposition
6. Gesten mit unruhiger Hand
- Akzeptanzkriterium: Grenzfälle werden korrekt abgelehnt

### 2.4.3 Gestenerkennung drahtlos

Test ID: UC4-W01

- Beschreibung: Drahtlose Gestenerkennung
- Testsetup: 2m Abstand, optimale Bedingungen
- Teststeps:
1. Drahtlos-Modus + Gestenerkennung aktiv
2. Alle 4 Gesten testen (je 10x)
- Akzeptanzkriterium: Identische Erkennungsrate wie kabelgebunden

# 3. Performance-Tests

## 3.1 Latenz-Messungen

### 3.1.1 End-to-End Latenz

Test ID: PERF-L01

17

- Beschreibung: Kabelgebundene End-to-End Latenz
- Testsetup: High-Speed-Kamera (240fps), Zeitstempel
- Teststeps:
1. Schnelle Fingerbewegung ausführen
2. Video-Analyse: Zeit zwischen Flexsensor-Bewegung und Servo-Reaktion
3. 100 Messungen für statistische Relevanz
4. Erwartetes Ergebnis: <50ms End-to-End
- Akzeptanzkriterium: 95% der Messungen <60ms

Test ID: PERF-L02

- Beschreibung: Drahtlose End-to-End Latenz
- Identische Testprozedur wie PERF-L01
- Akzeptanzkriterium: 95% der Messungen <75ms

### 3.1.2 Komponenten-Latenz-Aufschlüsselung

Test ID: PERF-L03

- Beschreibung: Latenz-Budget-Verifikation
- Messwerte:
- ADC-Lesezeit (A0-A4)
- Signal-Verarbeitungszeit
- Drahtlose Übertragungszeit (Sprint2)
- Servo-Ansteuerungszeit

18

- Akzeptanzkriterium: Summe entspricht End-to-End Messung ±10%

## 3.2 Genauigkeits-Tests

### 3.2.1 Positioniergenauigkeit

Test ID: PERF-A01

- Beschreibung: Statische Positionsgenauigkeit ·

Testsetup: Winkelmessgerät an Roboterfingern
Teststeps:
1. Flexsensor in definierte Position (30°, 60°, 90°, 120°, 150°)
2. Servo-Position messen
3. 10 Messungen pro Winkel
- Erwartetes Ergebnis: ±2° Abweichung
- Akzeptanzkriterium: 90% der Messungen innerhalb ±2°

Test ID: PERF-A02

- Beschreibung: Wiederholgenauigkeit

Teststeps:

4. 20x identische Fingerbewegung
5. Endposition-Streuung messen
- Akzeptanzkriterium: Standardabweichung <1°

19

### 3.2.2 Linearität und Kalibrierung

Test ID: PERF-A03

- Beschreibung: Linearitäts-Test
- Teststeps:
1. Flexsensor von 0° bis 180° in 10° Schritten
2. Servo-Position vs. Flexsensor-Position
3. Korrelations-Koeffizienten berechnen
- Akzeptanzkriterium: R² > 0.95

## 3.3 Stabilität und Zuverlässigkeit

### 3.3.1 Langzeit-Stabilität

Test ID: PERF-S01

- Beschreibung: 8-Stunden Dauerbetrieb
- Testsetup: Automatisierte Bewegungssequenz
- Teststeps:
1. Definierte Bewegungssequenz (5min Zyklus)
2. 8 Stunden kontinuierlicher Betrieb
3. Stündliche Performance-Messungen
- Messwerte: Latenz-Drift, Positions-Drift, Ausfallzeiten
- Akzeptanzkriterium: <5% Performance-Degradation

20

Test ID: PERF-S02

- Beschreibung: Thermische Stabilität
- Testsetup: Temperaturkammer 15°C bis 35°C
- Akzeptanzkriterium: Spezifikations-Erfüllung in gesamtem Temperaturbereich

### 3.3.2 Drahtlose Stabilität (Sprint 2)

Test ID: PERF-S03

- Beschreibung: Reichweiten-Performance ·

Teststeps:

1. Performance-Tests bei 1m, 2m, 3m, 4m, 5m
2. Je 30min Dauerbetrieb pro Distanz
- Messwerte: Paket-Verlust, Latenz-Variation, Verbindungsabbrüche
- Akzeptanzkriterium:
- 1-2m: <1% Paket-Verlust, <5% Latenz-Variation
- 3-5m: <5% Paket-Verlust, <15% Latenz-Variation

## 3.4 Energieeffizienz (Sprint 2)

Test ID: PERF-E01

- Beschreibung: Batterie-Laufzeit-Test
- Testsetup: Vollgeladene LiPo 7.4V 2200mAh
- Teststeps:
1. Kontinuierlicher Betrieb bis Batterie-Warnung

21

2. Stromverbrauch-Monitoring
- Erwartetes Ergebnis: >4 Stunden Betrieb
- Akzeptanzkriterium: >3.5 Stunden bei Standard-Nutzung

Test ID: PERF-E02

- Beschreibung: Power-Modi Vergleich
- Teststeps:
3. Normal-Modus (50Hz)
4. Power-Save-Modus (25Hz)
5. Emergency-Modus (10Hz)
- Messwerte: Stromverbrauch pro Modus
- Akzeptanzkriterium: Messungen entsprechen Spezifikation ±10%

# 4. Integrations- und Systemtests

## 4.1 Hardware-Software-Integration

### 4.1.1 Komponenten-Interaktion

Test ID: INT-H01

- Beschreibung: NRF24L01+ SPI-Integration
- Teststeps:
1. SPI-Kommunikation ohne Datenübertragung
2. Register-Lese/Schreib-Tests
3. Kontinuierliche Kommunikation mit anderen SPI-Geräten

22

- Akzeptanzkriterium: Keine SPI-Konflikte, stabile Kommunikation

Test ID: INT-H02

- Beschreibung: PWM-Servo Integration
- Teststeps:
4. Gleichzeitige PWM-Ausgabe auf alle 5 Servos
5. Interferenz-Messung zwischen PWM-Kanälen
6. Timing-Analyse der PWM-Signale
- Akzeptanzkriterium: Saubere PWM-Signale ohne Übersprechen

### 4.1.2 System-Bootstrapping

Test ID: INT-S01

- Beschreibung: System-Start-Sequenz
- Teststeps:
1. Cold-Boot beider Arduino-Systeme
2. Initialisierungs-Reihenfolge beobachten
3. Automatische Verbindungsherstellung
- Erwartetes Ergebnis: Vollständig funktionsfähig binnen 30s
- Akzeptanzkriterium: <30s bis voll betriebsbereit

23

## 4.2 End-to-End Systemtests

### 4.2.1 Realistische Nutzungsszenarien

Test ID: SYS-R01

- Beschreibung: Typische Benutzer-Session
- Testablauf:
1. System einschalten
2. Handschuh anziehen
3. Kalibrierung durchführen
4. 15 Minuten normale Nutzung (verschiedene Bewegungen)
5. Wechsel zwischen Kabel- und Drahtlos-Modus
6. Gestenerkennung-Session (5 Minuten)
7. System ausschalten
- Akzeptanzkriterium: Fehlerfreier Ablauf, Benutzer-Zufriedenheit

Test ID: SYS-R02

- Beschreibung: Multi-User-Wechsel
- Teststeps:
8. Benutzer A: Kalibrierung + 10min Nutzung
9. Benutzer B: Neue Kalibrierung + 10min Nutzung
10. Zurück zu Benutzer A: Alte Kalibrierung laden
- Akzeptanzkriterium: Kalibrierungs-Persistenz, schneller User-Switch

24

### 4.2.2 Stress-Szenarien

Test ID: SYS-S01

- Beschreibung: Rapid-Movement Stress-Test
- Teststeps:
1. Sehr schnelle Fingerbewegungen (2Hz)
2. 10 Minuten kontinuierlich
3. System-Verhalten beobachten
- Akzeptanzkriterium: Keine Systemhänger, akzeptable Folge-Performance

Test ID: SYS-S02

- Beschreibung: Interferenz-Stress (Sprint 2)
- Testsetup: Multiple WiFi-APs, Bluetooth-Geräte, Mikrowelle
- Teststeps:
4. Normale Funktion bei steigender Interferenz
5. Adaptive Kanal-Switching beobachten
- Akzeptanzkriterium: Maintainierte Funktionalität trotz Interferenz

25

# 5. Usability und Ergonomie-Tests

## 5.1 Benutzerfreundlichkeit

### 5.1.1 Setup und Kalibrierung

Test ID: USA-S01

- Beschreibung: Erstes Setup durch Laien-Benutzer
- Testpersonen: 5 Personen ohne Vorerfahrung
- Teststeps:
1. Handschuh anziehen (nur schriftliche Anleitung)
2. System einschalten
3. Kalibrierung durchführen
4. Erste Bewegungen
- Messwerte: Setup-Zeit, Anzahl Hilfestellungen, Erfolgsrate
- Akzeptanzkriterium: <10min Setup-Zeit, >80% Erfolgsrate ohne Hilfe

Test ID: USA-S02

- Beschreibung: Kalibrierungs-Qualität verschiedener Benutzer
- Testpersonen: 10 Personen, verschiedene Handgrößen
- Akzeptanzkriterium: Alle erreichen >90% Positionsgenauigkeit nach Kalibrierung

26

### 5.1.2 Alltagstauglichkeit

Test ID: USA-A01

- Beschreibung: Langzeit-Tragekomfort
- Teststeps:
1. 2-Stunden kontinuierliches Tragen
2. Komfort-Bewertung alle 30min
3. Hautirritationen prüfen
- Akzeptanzkriterium: Komfort-Rating >3/5 nach 2h

Test ID: USA-A02

- Beschreibung: Gestenerkennung Benutzerfreundlichkeit
- Teststeps:
4. 30min Gesten-Session pro Testperson
5. Erfolgsrate und Frustrations-Level messen
- Akzeptanzkriterium: >85% Gesten-Erfolgsrate, Frustration <2/5

## 5.2 LED-Interface Verständlichkeit

Test ID: USA-L01

- Beschreibung: LED-Status Interpretierbarkeit
- Teststeps:
1. Verschiedene LED-Zustände zeigen

27

2. Benutzer raten lassen ohne Anleitung
3. Mit Anleitung wiederholen
- Akzeptanzkriterium: >70% korrekte Interpretation ohne Anleitung

# 6. Sicherheits- und Robustheitstests

## 6.1 Elektrische Sicherheit

Test ID: SEC-E01

- Beschreibung: Spannungssicherheit bei LiPo-Betrieb
- Teststeps:
1. Überspannungs-Szenarien (9V)
2. Unterspannungs-Verhalten (<6V)
3. Kurzschluss-Protection
- Akzeptanzkriterium: Keine Schäden, sichere Abschaltung

Test ID: SEC-E02

- Beschreibung: Isolationsprüfung
- Teststeps:
4. Widerstandsmessung zwischen Spannungsdomänen
5. Berührungsschutz-Test
- Akzeptanzkriterium: >1MΩ Isolation, keine gefährlichen Spannungen

28

## 6.2 Mechanische Robustheit

Test ID: SEC-M01

- Beschreibung: Sturztest Handschuh-Einheit
- Teststeps:
1. 1m Fallhöhe auf harten Boden
2. 5 Stürze aus verschiedenen Orientierungen
3. Funktionstest nach jedem Sturz
- Akzeptanzkriterium: Volle Funktionalität nach allen Stürzen

Test ID: SEC-M02

- Beschreibung: Seilzug-Belastungstest
- Teststeps:
4. 200% Normalkraft auf Seilzug-System
5. 1000 Zyklen bei erhöhter Last
- Akzeptanzkriterium: Keine Seilrisse oder Beschädigungen

## 6.3 Drahtlose Sicherheit (Sprint 2)

Test ID: SEC-W01

- Beschreibung: Abhör-Resistenz
- Testsetup: RF-Monitoring Equipment · Teststeps:
1. Datenübertragung während externem RF-Monitoring

29

2. Analyse der übertragenen Daten
- Akzeptanzkriterium: Keine sensiblen Daten im Klartext übertragbar

Test ID: SEC-W02

- Beschreibung: Störsignal-Resistenz
- Teststeps:
3. Gezielte RF-Störsignale auf 2.4GHz
4. System-Verhalten bei Jamming
- Akzeptanzkriterium: Graceful Degradation, kein System-Crash

# 7. Automatisierte Test-Suites

## 7.1 Kontinuierliche Integration

Test Suite: CI-AUTO-01

- Beschreibung: Automatisierte Regressionstests
- Umfang:
- Hardware-Interface-Tests
- Basis-Funktionalitätstests (UC-1, UC-2)
- Performance-Monitoring
- Ausführung: Bei jeder Code-Änderung

30

- Dauer: <30 Minuten

Test Suite: CI-AUTO-02

- Beschreibung: Nächtliche Volltest-Suite
- Umfang:
- Alle automatisierbaren Tests
- Langzeit-Stabilität (4h)
- Performance-Benchmarks
- Ausführung: Täglich 22:00
- Dauer: 8 Stunden

## 7.2 Test-Automation-Framework

Komponenten:

- Test-Controller: Python-basierte Teststeuerung
- Hardware-Interface: Arduino-zu-PC Kommunikation
- Messdaten-Sammlung: Automatisierte Datenerfassung
- Report-Generierung: Standardisierte Test-Reports Automatisierung-Grad:
- Unit Tests: 95% automatisiert
- Integration Tests: 80% automatisiert
- System Tests: 60% automatisiert
- Usability Tests: 10% automatisiert (hauptsächlich manuell)

31

# 8. Qualitätssicherung (QA)

## 8.1 QA-Prozess

### 8.1.1 Test-Phasen

### 8.1.2 Qualitäts-Gates

Gate 1: Component Quality

- Kriterium: Alle Hardware-Komponenten einzeln funktional
- Tests: UC1-F01 bis UC1-F05, Hardware-Interface-Tests
- Freigabe-Schwelle: 100% Pass-Rate bei Komponententests

Gate 2: Integration Quality

Phase | Zeitrahmen | Verantwortlich | Exit-Kriterien
Unit Testing | Woche 1-2 | Entwickler | 95% Pass-Rate
Integration Testing | Woche 2-3 | QA-Team | Alle kritischen Tests bestanden
System Testing | Woche 3-4 | QA-Team + Benutzer | Spezifikations-Konformität
User Acceptance | Woche 4-5 | Endbenutzer | Benutzer-Zufriedenheit >4/5
Production Readiness | Woche 5 | Projekt-Lead | Alle Tests bestanden, Dokumentation vollständig

32

- Kriterium: Drahtlose und kabelgebundene Modi funktional
- Tests: UC1-W01, UC3-C01, INT-H01, INT-H02
- Freigabe-Schwelle: 95% Pass-Rate bei Integrationstests

Gate 3: System Quality

- Kriterium: Vollständige Use Case Abdeckung
- Tests: Alle UC-Tests, Performance-Tests, Usability-Tests
- Freigabe-Schwelle: 90% Pass-Rate, alle kritischen Tests bestanden

Gate 4: Production Quality

- Kriterium: Produktions-Readiness und Langzeit-Stabilität
- Tests: Stress-Tests, Sicherheitstests, 8h-Dauerbetrieb
- Freigabe-Schwelle: Spezifikations-Konformität, Sicherheits-Compliance

33

## 8.2 Defect Management

### 8.2.1 Bug-Klassifikation

Severity | Definition | Reaktionszeit | Beispiele
BLOCKER | System unbrauchbar | Sofort | Kompletter System-Ausfall, Sicherheitsrisiko
CRITICAL | Hauptfunktion betroffen | <4h | UC-Ausfall, drahtlose Kommunikation tot
MAJOR | Wichtige Funktion betroffen | <24h | Gestenerkennung fehlerhaft, Performance-Einbruch
MINOR | Nebenfunktion betroffen | <72h | LED-Anzeige falsch, Usability-Problem
TRIVIAL | Kosmetisches Problem | <1 Woche | Dokumentations-Fehler, nicht-kritische UI-Probleme

34

### 8.2.2 Bug-Lifecycle

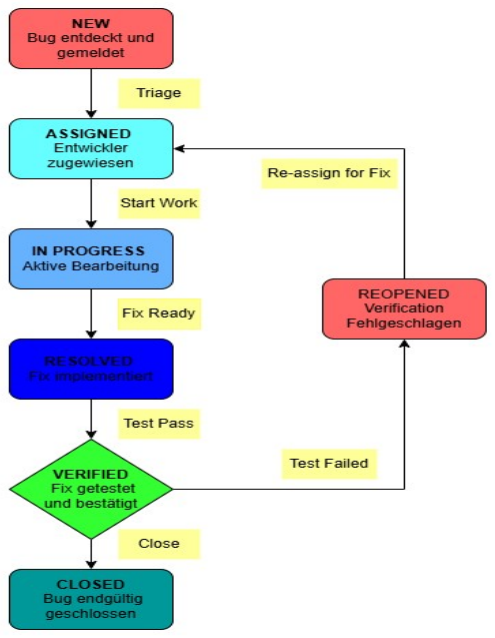
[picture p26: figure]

35

Bug-Tracking-Metriken:

- Bug-Detection-Rate: Anzahl Bugs pro Testphase
- Bug-Resolution-Time: Durchschnittliche Behebungszeit nach Severity
- Bug-Escape-Rate: Bugs die erst in späteren Phasen gefunden werden
- Reopen-Rate: Anteil der nach Behebung wiedereröffneten Bugs

## 8.3Testdaten-Management

### 8.3.1 Kalibrierungsdaten-Sets

Standard-Kalibrierdaten:

- Kleine Hand: Weiblich, Handspanne <18cm
- Mittlere Hand: Standard, Handspanne 18-20cm
- Große Hand: Männlich, Handspanne >20cm
- Extremfälle: Sehr lange/kurze Finger, arthritische Einschränkungen Test-

Kalibrierdaten:

- Minimale Werte: Sensoren bei minimaler Beugung
- Maximale Werte: Sensoren bei maximaler Beugung
- Edge-Cases: Grenzwerte für Algorithmus-Testing
- Invalid-Data: Bewusst fehlerhafte Daten für Robustheitstests

### 8.3.2 Performance-Baselines

Sprint 1 Baseline (Referenz):

36

- Latenz: 45ms ±5ms End-to-End
- Genauigkeit: ±1.5° bei optimalen Bedingungen
- Stabilität: 6h MTBF-Sprint 2 Targets:
- Latenz kabelgebunden: <50ms (10% Toleranz vs Sprint 1)
- Latenz drahtlos: <75ms
- Genauigkeit: ±2° (leichte Verschlechterung akzeptiert)
- Gestenerkennung: >90% Accuracy
- Drahtlos-Stabilität: >95% bei 2m, >85% bei 5m

## 8.4 Test-Reporting

### 8.4.1 Daily Test Reports

Automatisch generiert:

- Pass/Fail Summary: Aktueller Status aller automatisierten Tests
- Performance Trends: Latenz, Genauigkeit, Stabilität über Zeit
- Regression Detection: Vergleich zu vorherigen Versionen
- Critical Issues: Neue BLOCKER/CRITICAL Bugs Manually Review:
- Test-Fortschritt: % Completion der Test-Suites
- Quality-Trends: Verbesserung/Verschlechterung über Zeit
- Risk-Assessment: Aktuelle Risiken für Release

### 8.4.2 Weekly QA Summary

Executive Dashboard:

37

- Overall Quality Score: Gewichtete Bewertung aller QA-Metriken
- Release-Readiness: Ampel-Status für geplanten Release
- Top Issues: Die 5 kritischsten offenen Probleme
- Test Coverage: Abdeckung aller Spezifikations-Anforderungen

Technical Details:

- Test-Execution-Statistik: Anzahl Tests pro Kategorie
- Performance-Benchmarks: Vergleich aktueller vs. Target-Werte
- Code-Quality-Metriken: Komplexität, Test-Coverage, Code-Smells
- Hardware-Reliability: MTBF, Ausfallstatistiken

## 8.5 Compliance und Standards

### 8.5.1 Technische Standards

Elektrische Sicherheit:

- IEC 62368-1: Audio/Video, Informations- und Kommunikationstechnik
- IEC 61000-6-3: EMV-Störaussendung für Wohnbereich
- IEC 61000-6-1: EMV-Störfestigkeit für Wohnbereich

Drahtlose Kommunikation:

- ETSI EN 300 328: 2.4GHz ISM Band Requirements
- FCC Part 15.247: Spread Spectrum Transmitters
- IC RSS-247: 2.4GHz Band Regulations Medizinprodukte (falls applicable):
- ISO 13485: Quality Management für Medizinprodukte

38

- IEC 62304: Medical Device Software Lifecycle

### 8.5.2 Test-Standard-Compliance

Functional Testing:

- ISO/IEC 25010: Systems und Software Quality Model
- IEEE 829: Software Test Documentation Standard Performance Testing:
- ISO/IEC 25023: System und Software Quality Measurements
- IEEE 2857: Privacy Engineering für Software Usability Testing:
- ISO 9241-11: Ergonomics - Usability Definitions und Concepts
- IEC 62366-1: Medical Devices - Usability Engineering

# 9. Test-Infrastruktur und Tools

## 9.1 Hardware-Testumgebung

### 9.1.1 Laborausstattung

Messtechnik:

- Oszilloskop: 4-Kanal, 200MHz, für Signal-Analyse
- Multimeter: Präzisions-DMM für Spannungs/Strom-Messungen
- RF-Analyzer: 2.4GHz Spektrum-Analyse für drahtlose Tests
- High-Speed-Kamera: 240fps für Latenz-Messungen

39

- Winkelmesser: Digitale Protraktoren für Servo-Position-Verifikation Testaufbau-

Hardware:

- Automatisierte Testbank: Mechanische Finger-Bewegungs-Simulation
- RF-Anechoic Chamber: Störungsfreie Funktest-Umgebung
- Klimakammer: Temperatur-/Feuchtigkeits-Tests (-10°C bis +50°C)
- Vibrationstisch: Mechanische Belastungstests
- EMV-Testkammer: Elektromagnetische Verträglichkeitsprüfung

### 9.1.2 Test-Automatisierung-Hardware

Arduino-Test-Interface:

- Test-Controller-Board: Speziell entwickelt für automatisierte Tests
- Multiplexer-Arrays: Automatische Umschaltung zwischen Test-Setups
- Sensor-Simulatoren: Präzise ADC-Wert-Generierung für Flexsensor-Simulation
- Load-Banks: Kontrollierte Last-Simulation für Servo-Tests

## 9.2 Software-Testtools

### 9.2.1 Test-Framework

Kernfunktionen:

- Automated Test Execution: Sequentielle Abarbeitung aller Test-Suites
- Real-time Monitoring: Live-Überwachung während Tests
- Data Collection: Automatische Messdaten-Erfassung

40

- Statistical Analysis: Trend-Analyse und Performance-Benchmarking
- Report Generation: HTML/PDF-Reports mit Visualisierungen
- Test-Automation-Suite (Python-basiert):

41

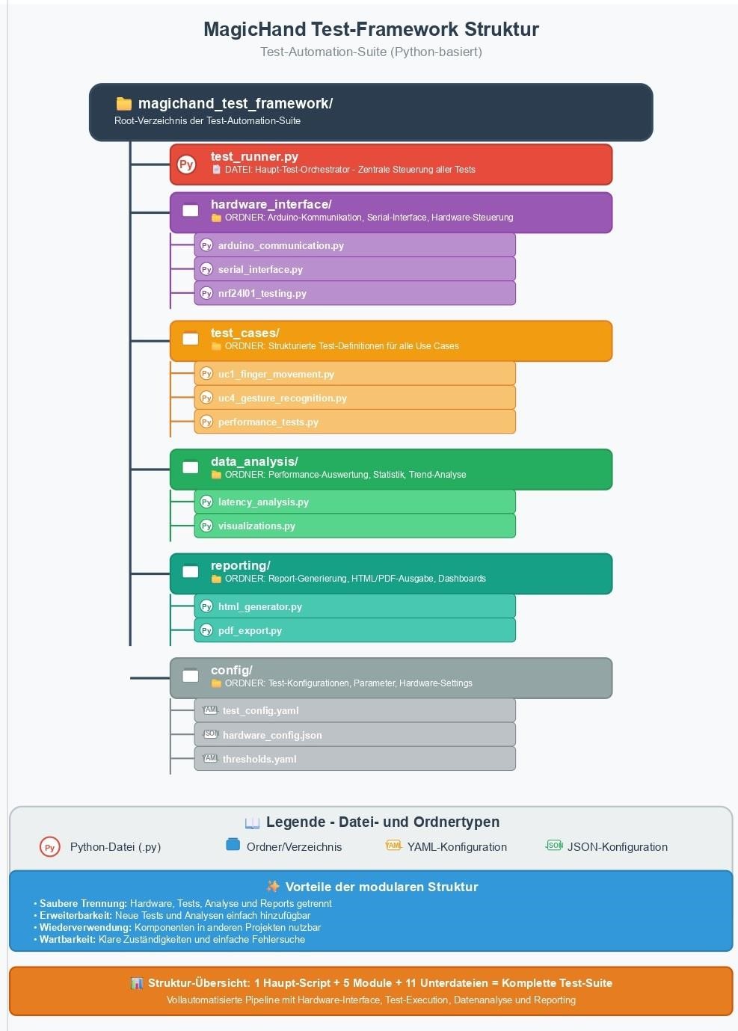
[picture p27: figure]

42
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

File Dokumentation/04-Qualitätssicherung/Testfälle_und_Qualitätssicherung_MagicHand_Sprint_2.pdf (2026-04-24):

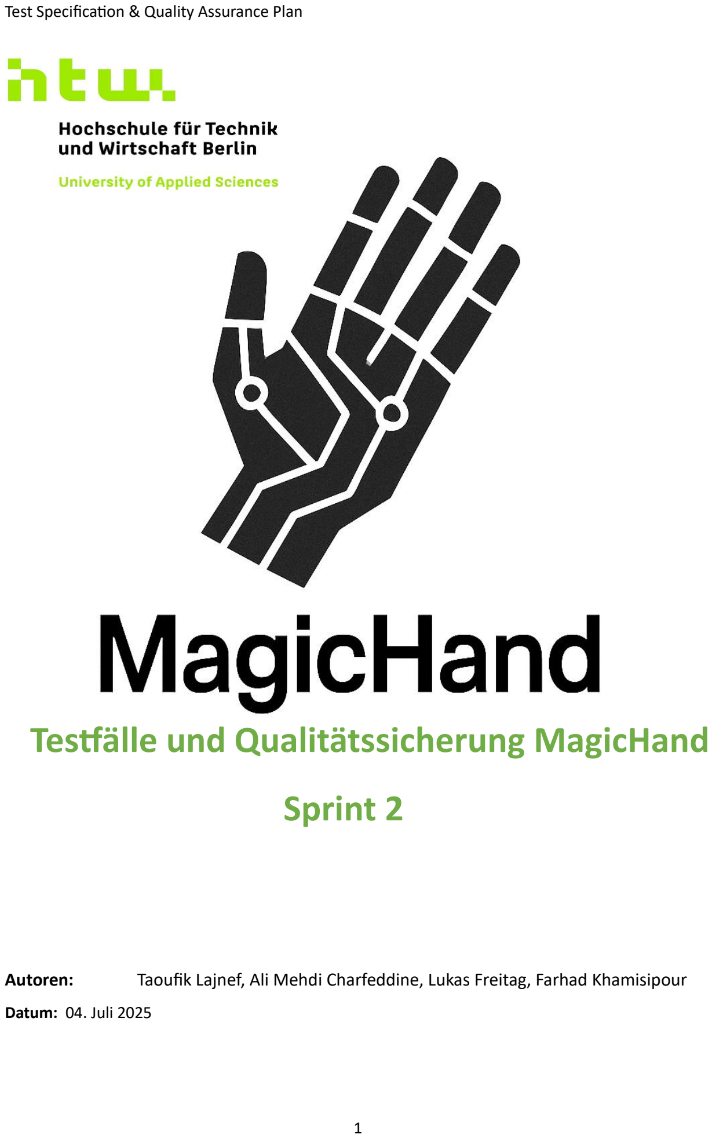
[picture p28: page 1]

Test Specification & Quality Assurance Plan

1

# Testfälle und Qualitätssicherung MagicHand

# Sprint 2

Autoren: | Taoufik Lajnef, Ali Mehdi Charfeddine, Lukas Freitag, Farhad Khamisipour

Datum: 04. Juli 2025

2

## Table of Contents

3

4

5

6

7

# 1. Testplan-Übersicht

## 1.1 Teststrategie Sprint 2

Testziele:

- Verifikation aller Use Cases (UC-1 bis UC-4)
- Validierung der Sprint 2 Erweiterungen (Drahtlos + Gestenerkennung)
- Performance-Nachweis der spezifizierten Kennwerte
- Qualitätssicherung für Produktions-Readiness

Testumfang Sprint 1+2:

- Funktionale Tests: Alle definierten Use Cases und Features
- Performance Tests: Latenz, Genauigkeit, Stabilität
- Integrationstests: Hardware-Software-Zusammenspiel
- Systemtests: End-to-End Szenarien
- Usability Tests: Benutzerfreundlichkeit und Ergonomie
- Stress Tests: Grenzwerte und Ausfallverhalten
- Sicherheitstests: Drahtlose Kommunikation und Datenschutz
1.2 | Testarten-Matrix
Testtyp | Sprint 1 | Sprint 2 NEU | Priorität | Aufwand | Automatisierung
Unit Tests | Hardware-Komponenten | NRF24L01+, Gestenerkennung | Hoch | 30% | Teilweise
Integrationstests | Sensor-Servo-Kopplung | Drahtlose Kommunikation | Hoch | 25% | Ja
Systemtests | End-to-End Bewegung | Komplette drahtlose Kette | Kritisch | 20% | Teilweise
Performance Tests | Latenz, Genauigkeit | Funkreichweite, Batterie | Hoch | 15% | Ja
Usability Tests | Handschuh-Ergonomie | Gestenbedienung | Mittel | 10% | Nein

8

## 1.3 Testumgebung

Hardware-Testsetup:

- Primär-Setup: Vollständiges MagicHand System Sprint 2
- Backup-Setup: Sprint 1 System für Vergleichstests
- Messgeräte: Oszilloskop, Multimeter, RF-Analyzer, Kamera (120fps)
- Testumgebung: Laborraum 20°C, störungsarme 2.4GHz Umgebung

Software-Testtools:

- Arduino IDE: Serial Monitor für Debug-Ausgaben
- Testframework: Strukturierte Testprotokolle
- Messtool-Suite: Python-Skripte für automatisierte Messungen
- Dokumentation: Testprotokoll-Templates

# 2. Funktionale Testfälle

## 2.1 UC-1: Fingerbewegung übertragen (Sprint 1+2)

### 2.1.1 Einzelfinger-Tests

Test ID: UC1-F01

- Beschreibung: Daumen-Bewegung isoliert testen
- Vorbedingung: System kalibriert, Handschuh korrekt angelegt
- Teststeps:
1. Daumen langsam von 0° bis 90° beugen
2. Position 5 Sekunden halten
3. Daumen zurück in Ausgangsposition
- Erwartetes Ergebnis: Roboter-Daumen folgt exakt mit ±2° Genauigkeit
- Messwerte: Servo-Position, Latenz, Stabilität

9

- Akzeptanzkriterium: Latenz <60ms, Genauigkeit ±2°

Test ID: UC1-F02 bis UC1-F05

- Analog für: Zeigefinger, Mittelfinger, Ringfinger, Kleiner Finger
- Identische Testprozedur mit fingerspezifischen Erwartungen

### 2.1.2 Multi-Finger-Tests

Test ID: UC1-M01

- Beschreibung: Simultane Bewegung aller 5 Finger
- Teststeps:
1. Alle Finger gleichzeitig langsam zur Faust schließen
2. 3 Sekunden halten
3. Finger gleichzeitig öffnen
- Erwartetes Ergebnis: Synchrone Roboterhand-Bewegung
- Messwerte: Synchronisation-Offset zwischen Fingern
- Akzeptanzkriterium: Max. 10ms Offset zwischen Fingern

Test ID: UC1-M02

- Beschreibung: Komplexe Fingerkombinationen
- Teststeps:
1. Victory-Sign (Zeige + Mittelfinger)
2. Rock-Sign (Zeige + Kleiner Finger)
3. Okay-Sign (Daumen + Zeigefinger)
- Akzeptanzkriterium: Korrekte Fingerpositionen ±3°

### 2.1.3 Drahtlose Übertragung (Sprint 2 NEU)

Test ID: UC1-W01

- Beschreibung: Drahtlose Übertragung bei optimalen Bedingungen
- Testsetup: 1m Abstand, keine Interferenz
- Teststeps:

10

1. Drahtlos-Modus aktivieren
2. Verbindung etablieren
3. Fingerbewegungen wie bei UC1-F01-F05
- Erwartetes Ergebnis: Identische Performance wie kabelgebunden
- Akzeptanzkriterium: Latenz <75ms, Paket-Verlust <2%

Test ID: UC1-W02

- Beschreibung: Reichweiten-Test
- Teststeps:
1. Test bei 1m, 2m, 3m, 4m, 5m Distanz
2. Bei jeder Distanz: 50 Fingerbewegungen
- Messwerte: RSSI, Paket-Verlust, Latenz
- Akzeptanzkriterium: Bis 2m: <2% Verlust, bis 5m: <5% Verlust

## 2.2 UC-2: Hand öffnen/schließen (Sprint 1+2)

Test ID: UC2-01

- Beschreibung: Vollständiges Öffnen der Hand
- Teststeps:
1. Hand komplett zur Faust schließen
2. Langsam alle Finger strecken
3. Maximale Öffnung erreichen
- Erwartetes Ergebnis: Alle Roboterfinger gestreckt
- Messwerte: Endposition aller Servos
- Akzeptanzkriterium: Alle Servos bei 0° ±5°

Test ID: UC2-02

- Beschreibung: Graduelles Schließen
- Teststeps:
1. Hand offen starten
2. Stufenweise schließen (25%, 50%, 75%, 100%)
3. Bei jeder Stufe 2 Sekunden verweilen

11

- Akzeptanzkriterium: Proportionale Roboterhand-Bewegung

Test ID: UC2-W01

- Beschreibung: Hand öffnen/schließen drahtlos
- Testsetup: 3m Abstand, normale Umgebung
- Akzeptanzkriterium: Identisches Verhalten wie kabelgebunden

## 2.3 UC-3: Verbindung herstellen (Sprint 2 NEU)

### 2.3.1 Verbindungsaufbau

Test ID: UC3-C01

- Beschreibung: Erstverbindung von Kalt-Start
- Teststeps:
1. Beide Arduino-Systeme einschalten
2. Automatischen Verbindungsaufbau beobachten
3. Verbindungszeit messen
- Erwartetes Ergebnis: Verbindung binnen 10 Sekunden
- Messwerte: Connection-Time, RSSI, Channel
- Akzeptanzkriterium: <10s Verbindungszeit, RSSI >-85dBm

Test ID: UC3-C02

- Beschreibung: Wiederverbindung nach Unterbrechung
- Teststeps:
1. Stabile Verbindung etablieren
2. Empfänger kurz ausschalten (5s)
3. Empfänger wieder einschalten
4. Wiederverbindungszeit messen
- Akzeptanzkriterium: <3s Wiederverbindung

12

### 2.3.2 Verbindungsqualität

Test ID: UC3-Q01

- Beschreibung: Stabilität bei Bewegung
- Teststeps:
1. Verbindung bei 2m etablieren
2. Sender langsam bewegen (links/rechts/vor/zurück)
3. Kontinuierliche Bewegungsübertragung
- Messwerte: RSSI-Schwankung, Paket-Verlust
- Akzeptanzkriterium: RSSI-Variation <15dB, Verlust <5%

Test ID: UC3-Q02

- Beschreibung: Interferenz-Resistenz
- Testsetup: WiFi-Router, Bluetooth-Geräte als Störquellen
- Teststeps:
1. Baseline-Messung ohne Störer
2. WiFi-Router auf Kanal 6 aktivieren (2.437GHz)
3. Bluetooth-Geräte in der Nähe
- Akzeptanzkriterium: <10% Performance-Degradation

### 2.3.3 Kanalwechsel und Adaptive Features

Test ID: UC3-A01

- Beschreibung: Automatischer Kanalwechsel
- Teststeps:
1. Verbindung auf Kanal 76 etablieren
2. Künstliche Interferenz auf Kanal 76 erzeugen
3. Automatischen Kanalwechsel beobachten
- Erwartetes Ergebnis: Wechsel zu freiem Kanal binnen 5s
- Akzeptanzkriterium: <5s Channel-Switch, <3s Service-Unterbrechung

13

## 2.4 UC-4: Gesten erkennen (Sprint 2 NEU)

### 2.4.1 Grundlegende Gestenerkennung

Test ID: UC4-G01

- Beschreibung: Victory-Geste (✌️) erkennen
- Teststeps:
1. Gestenerkennung aktivieren (Mode-Switch >3s)
2. Victory-Geste korrekt formen
3. 1.5 Sekunden stabil halten
4. Roboterhand-Reaktion beobachten
- Erwartetes Ergebnis: Lila LED kurz auf, Roboterhand macht Victory
- Akzeptanzkriterium: >90% Erkennungsrate bei 20 Versuchen

Test ID: UC4-G02 bis UC4-G04

- Analog für: Okay (👌), Point (👉), Thumbs-Up (👍)
- Identische Testprozedur mit gestenspezifischen Parametern

### 2.4.2 Robustheit der Gestenerkennung

Test ID: UC4-R01

- Beschreibung: False-Positive Test
- Teststeps:
1. Gestenerkennung aktivieren
2. 50 zufällige Handbewegungen (keine definierten Gesten)
3. False-Positive-Erkennungen zählen
- Akzeptanzkriterium: <5% False-Positive-Rate

Test ID: UC4-R02

- Beschreibung: Grenzfall-Gesten
- Teststeps:
1. Gesten mit nur 0.8s Haltezeit

14

2. Gesten mit leicht falscher Fingerposition
3. Gesten mit unruhiger Hand
- Akzeptanzkriterium: Grenzfälle werden korrekt abgelehnt

### 2.4.3 Gestenerkennung drahtlos

Test ID: UC4-W01

- Beschreibung: Drahtlose Gestenerkennung
- Testsetup: 2m Abstand, optimale Bedingungen
- Teststeps:
1. Drahtlos-Modus + Gestenerkennung aktiv
2. Alle 4 Gesten testen (je 10x)
- Akzeptanzkriterium: Identische Erkennungsrate wie kabelgebunden

# 3. Performance-Tests

## 3.1 Latenz-Messungen

### 3.1.1 End-to-End Latenz

Test ID: PERF-L01

- Beschreibung: Kabelgebundene End-to-End Latenz
- Testsetup: High-Speed-Kamera (240fps), Zeitstempel
- Teststeps:
1. Schnelle Fingerbewegung ausführen
2. Video-Analyse: Zeit zwischen Flexsensor-Bewegung und Servo-Reaktion
3. 100 Messungen für statistische Relevanz
- Erwartetes Ergebnis: <50ms End-to-End
- Akzeptanzkriterium: 95% der Messungen <60ms

Test ID: PERF-L02

- Beschreibung: Drahtlose End-to-End Latenz

15

- Identische Testprozedur wie PERF-L01
- Akzeptanzkriterium: 95% der Messungen <75ms

### 3.1.2 Komponenten-Latenz-Aufschlüsselung

Test ID: PERF-L03

- Beschreibung: Latenz-Budget-Verifikation
- Messwerte:
- ADC-Lesezeit (A0-A4)
- Signal-Verarbeitungszeit
- Drahtlose Übertragungszeit (Sprint 2)
- Servo-Ansteuerungszeit
- Akzeptanzkriterium: Summe entspricht End-to-End Messung ±10%

## 3.2 Genauigkeits-Tests

### 3.2.1 Positioniergenauigkeit

Test ID: PERF-A01

- Beschreibung: Statische Positionsgenauigkeit
- Testsetup: Winkelmessgerät an Roboterfingern
- Teststeps:
1. Flexsensor in definierte Position (30°, 60°, 90°, 120°, 150°)
2. Servo-Position messen
3. 10 Messungen pro Winkel
- Erwartetes Ergebnis: ±2° Abweichung
- Akzeptanzkriterium: 90% der Messungen innerhalb ±2°

Test ID: PERF-A02

- Beschreibung: Wiederholgenauigkeit
- Teststeps:
1. 20x identische Fingerbewegung
2. Endposition-Streuung messen

16

- Akzeptanzkriterium: Standardabweichung <1°

### 3.2.2 Linearität und Kalibrierung

Test ID: PERF-A03

- Beschreibung: Linearitäts-Test
- Teststeps:
1. Flexsensor von 0° bis 180° in 10° Schritten
2. Servo-Position vs. Flexsensor-Position
3. Korrelations-Koeffizienten berechnen
- Akzeptanzkriterium: R² > 0.95

## 3.3 Stabilität und Zuverlässigkeit

### 3.3.1 Langzeit-Stabilität

Test ID: PERF-S01

- Beschreibung: 8-Stunden Dauerbetrieb
- Testsetup: Automatisierte Bewegungssequenz
- Teststeps:
1. Definierte Bewegungssequenz (5min Zyklus)
2. 8 Stunden kontinuierlicher Betrieb
3. Stündliche Performance-Messungen
- Messwerte: Latenz-Drift, Positions-Drift, Ausfallzeiten
- Akzeptanzkriterium: <5% Performance-Degradation

Test ID: PERF-S02

- Beschreibung: Thermische Stabilität
- Testsetup: Temperaturkammer 15°C bis 35°C
- Akzeptanzkriterium: Spezifikations-Erfüllung in gesamtem Temperaturbereich

17

### 3.3.2 Drahtlose Stabilität (Sprint 2)

Test ID: PERF-S03

- Beschreibung: Reichweiten-Performance
- Teststeps:
1. Performance-Tests bei 1m, 2m, 3m, 4m, 5m
2. Je 30min Dauerbetrieb pro Distanz
- Messwerte: Paket-Verlust, Latenz-Variation, Verbindungsabbrüche
- Akzeptanzkriterium:
- 1-2m: <1% Paket-Verlust, <5% Latenz-Variation
- 3-5m: <5% Paket-Verlust, <15% Latenz-Variation

## 3.4 Energieeffizienz (Sprint 2)

Test ID: PERF-E01

- Beschreibung: Batterie-Laufzeit-Test
- Testsetup: Vollgeladene LiPo 7.4V 2200mAh
- Teststeps:
1. Kontinuierlicher Betrieb bis Batterie-Warnung
2. Stromverbrauch-Monitoring
- Erwartetes Ergebnis: >4 Stunden Betrieb
- Akzeptanzkriterium: >3.5 Stunden bei Standard-Nutzung

Test ID: PERF-E02

- Beschreibung: Power-Modi Vergleich
- Teststeps:
1. Normal-Modus (50Hz)
2. Power-Save-Modus (25Hz)
3. Emergency-Modus (10Hz)
- Messwerte: Stromverbrauch pro Modus
- Akzeptanzkriterium: Messungen entsprechen Spezifikation ±10%

18

# 4. Integrations- und Systemtests

## 4.1 Hardware-Software-Integration

### 4.1.1 Komponenten-Interaktion

Test ID: INT-H01

- Beschreibung: NRF24L01+ SPI-Integration
- Teststeps:
1. SPI-Kommunikation ohne Datenübertragung
2. Register-Lese/Schreib-Tests
3. Kontinuierliche Kommunikation mit anderen SPI-Geräten
- Akzeptanzkriterium: Keine SPI-Konflikte, stabile Kommunikation

Test ID: INT-H02

- Beschreibung: PWM-Servo Integration
- Teststeps:
1. Gleichzeitige PWM-Ausgabe auf alle 5 Servos
2. Interferenz-Messung zwischen PWM-Kanälen
3. Timing-Analyse der PWM-Signale
- Akzeptanzkriterium: Saubere PWM-Signale ohne Übersprechen

### 4.1.2 System-Bootstrapping

Test ID: INT-S01

- Beschreibung: System-Start-Sequenz
- Teststeps:
1. Cold-Boot beider Arduino-Systeme
2. Initialisierungs-Reihenfolge beobachten
3. Automatische Verbindungsherstellung
- Erwartetes Ergebnis: Vollständig funktionsfähig binnen 30s

19

- Akzeptanzkriterium: <30s bis voll betriebsbereit

## 4.2 End-to-End Systemtests

### 4.2.1 Realistische Nutzungsszenarien

Test ID: SYS-R01

- Beschreibung: Typische Benutzer-Session
- Testablauf:
1. System einschalten
2. Handschuh anziehen
3. Kalibrierung durchführen
4. 15 Minuten normale Nutzung (verschiedene Bewegungen)
5. Wechsel zwischen Kabel- und Drahtlos-Modus
6. Gestenerkennung-Session (5 Minuten)
7. System ausschalten
- Akzeptanzkriterium: Fehlerfreier Ablauf, Benutzer-Zufriedenheit

Test ID: SYS-R02

- Beschreibung: Multi-User-Wechsel
- Teststeps:
1. Benutzer A: Kalibrierung + 10min Nutzung
2. Benutzer B: Neue Kalibrierung + 10min Nutzung
3. Zurück zu Benutzer A: Alte Kalibrierung laden
- Akzeptanzkriterium: Kalibrierungs-Persistenz, schneller User-Switch

### 4.2.2 Stress-Szenarien

Test ID: SYS-S01

- Beschreibung: Rapid-Movement Stress-Test
- Teststeps:
1. Sehr schnelle Fingerbewegungen (2Hz)
2. 10 Minuten kontinuierlich

20

3. System-Verhalten beobachten
- Akzeptanzkriterium: Keine Systemhänger, akzeptable Folge-Performance

Test ID: SYS-S02

- Beschreibung: Interferenz-Stress (Sprint 2)
- Testsetup: Multiple WiFi-APs, Bluetooth-Geräte, Mikrowelle
- Teststeps:
1. Normale Funktion bei steigender Interferenz
2. Adaptive Kanal-Switching beobachten
- Akzeptanzkriterium: Maintainierte Funktionalität trotz Interferenz

# 5.Usability und Ergonomie-Tests

## 5.1 Benutzerfreundlichkeit

### 5.1.1 Setup und Kalibrierung

Test ID: USA-S01

- Beschreibung: Erstes Setup durch Laien-Benutzer
- Testpersonen: 5 Personen ohne Vorerfahrung
- Teststeps:
1. Handschuh anziehen (nur schriftliche Anleitung)
2. System einschalten
3. Kalibrierung durchführen
4. Erste Bewegungen
- Messwerte: Setup-Zeit, Anzahl Hilfestellungen, Erfolgsrate
- Akzeptanzkriterium: <10min Setup-Zeit, >80% Erfolgsrate ohne Hilfe

Test ID: USA-S02

- Beschreibung: Kalibrierungs-Qualität verschiedener Benutzer
- Testpersonen: 10 Personen, verschiedene Handgrößen
- Akzeptanzkriterium: Alle erreichen >90% Positionsgenauigkeit nach Kalibrierung

21

### 5.1.2 Alltagstauglichkeit

Test ID: USA-A01

- Beschreibung: Langzeit-Tragekomfort
- Teststeps:
1. 2-Stunden kontinuierliches Tragen
2. Komfort-Bewertung alle 30min
3. Hautirritationen prüfen
- Akzeptanzkriterium: Komfort-Rating >3/5 nach 2h

Test ID: USA-A02

- Beschreibung: Gestenerkennung Benutzerfreundlichkeit
- Teststeps:
1. 30min Gesten-Session pro Testperson
2. Erfolgsrate und Frustrations-Level messen
- Akzeptanzkriterium: >85% Gesten-Erfolgsrate, Frustration <2/5

## 5.2 LED-Interface Verständlichkeit

Test ID: USA-L01

- Beschreibung: LED-Status Interpretierbarkeit
- Teststeps:
1. Verschiedene LED-Zustände zeigen
2. Benutzer raten lassen ohne Anleitung
3. Mit Anleitung wiederholen
- Akzeptanzkriterium: >70% korrekte Interpretation ohne Anleitung

22

# 6. Sicherheits- und Robustheitstests

## 6.1 Elektrische Sicherheit

Test ID: SEC-E01

- Beschreibung: Spannungssicherheit bei LiPo-Betrieb
- Teststeps:
1. Überspannungs-Szenarien (9V)
2. Unterspannungs-Verhalten (<6V)
3. Kurzschluss-Protection
- Akzeptanzkriterium: Keine Schäden, sichere Abschaltung

Test ID: SEC-E02

- Beschreibung: Isolationsprüfung
- Teststeps:
1. Widerstandsmessung zwischen Spannungsdomänen
2. Berührungsschutz-Test
- Akzeptanzkriterium: >1MΩ Isolation, keine gefährlichen Spannungen

## 6.2 Mechanische Robustheit

Test ID: SEC-M01

- Beschreibung: Sturztest Handschuh-Einheit
- Teststeps:
1. 1m Fallhöhe auf harten Boden
2. 5 Stürze aus verschiedenen Orientierungen
3. Funktionstest nach jedem Sturz
- Akzeptanzkriterium: Volle Funktionalität nach allen Stürzen

Test ID: SEC-M02

- Beschreibung: Seilzug-Belastungstest
- Teststeps:

23

1. 200% Normalkraft auf Seilzug-System
2. 1000 Zyklen bei erhöhter Last
- Akzeptanzkriterium: Keine Seilrisse oder Beschädigungen

## 6.3 Drahtlose Sicherheit (Sprint 2)

Test ID: SEC-W01

- Beschreibung: Abhör-Resistenz
- Testsetup: RF-Monitoring Equipment
- Teststeps:
1. Datenübertragung während externem RF-Monitoring
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

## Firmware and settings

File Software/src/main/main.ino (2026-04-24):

#include <Servo.h>
#include "servo_controller.h"
#include "config.h"

ServoController servoController;

void setup() {
    Serial.begin(SERIAL_BAUD);
    
    #if DEBUG_MODE
    Serial.println("Starting Servo-Flex Controller...");
    #endif
    
    servoController.initialize();
    
    #if DEBUG_MODE
    Serial.println("Setup complete!");
    Serial.println("Flex readings format: [flex1, flex2, flex3, flex4, flex5]");
    #endif
}

void loop() {
    // Read all flex sensors and control servos
    for(int i = 0; i < NUM_SERVOS; i++) {
        int flexReading = analogRead(FLEX_PINS[i]);
        int servoPosition = servoController.calculatePosition(i, flexReading);
        servoController.moveServo(i, servoPosition);
    }
    
    #if DEBUG_MODE
    printFlexReadings();
    #endif
    
    delay(LOOP_DELAY);
}

void printFlexReadings() {
    Serial.print("Flex readings: [");
    for(int i = 0; i < NUM_SERVOS; i++) {
        Serial.print(analogRead(FLEX_PINS[i]));
        if(i < NUM_SERVOS - 1) {
            Serial.print(", ");
        }
    }
    Serial.println("]");
}

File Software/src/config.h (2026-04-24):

#ifndef CONFIG_H
#define CONFIG_H

// Hardware configuration
#define NUM_SERVOS 5
#define LOOP_DELAY 300

// Servo pins
const int SERVO_PINS[NUM_SERVOS] = {2, 3, 4, 5, 6};

// Flex sensor pins
const int FLEX_PINS[NUM_SERVOS] = {A1, A2, A3, A4, A5};

// Calibration data for each flex sensor
const int FLEX_MIN_VALUES[NUM_SERVOS] = {840, 879, 828, 874, 855};
const int FLEX_MAX_VALUES[NUM_SERVOS] = {900, 882, 824, 878, 851};

// Servo angle mappings (some inverted)
const int SERVO_MIN_ANGLES[NUM_SERVOS] = {180, 0, 180, 0, 180};
const int SERVO_MAX_ANGLES[NUM_SERVOS] = {0, 180, 0, 180, 0};

// Debug settings
#define DEBUG_MODE true
#define SERIAL_BAUD 9600

#endif

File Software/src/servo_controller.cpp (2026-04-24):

#include "servo_controller.h"

void ServoController::initialize()
{
    for (int i = 0; i < NUM_SERVOS; i++)
    {
        servos[i].attach(SERVO_PINS[i]);
        currentPositions[i] = 90; // Start at middle position
        servos[i].write(90);
    }

#if DEBUG_MODE
    Serial.println("ServoController initialized");
#endif

    delay(1000); // Allow servos to reach initial position
}

int ServoController::calculatePosition(int servoIndex, int flexReading)
{
    if (!isValidServoIndex(servoIndex))
    {
        return 90; // Default to middle position
    }

    // Map flex reading to servo angle
    int position = map(flexReading,
                       FLEX_MIN_VALUES[servoIndex],
                       FLEX_MAX_VALUES[servoIndex],
                       SERVO_MIN_ANGLES[servoIndex],
                       SERVO_MAX_ANGLES[servoIndex]);

    // Constrain to valid servo range
    position = constrain(position, 0, 180);

    return position;
}

void ServoController::moveServo(int servoIndex, int position)
{
    if (!isValidServoIndex(servoIndex) || !isValidPosition(position))
    {
        return;
    }

    servos[servoIndex].write(position);
    currentPositions[servoIndex] = position;

#if DEBUG_MODE
    Serial.print("Servo ");
    Serial.print(servoIndex);
    Serial.print(" moved to ");
    Serial.println(position);
#endif
}

bool ServoController::isValidPosition(int position)
{
    return (position >= 0 && position <= 180);
}

bool ServoController::isValidServoIndex(int index)
{
    return (index >= 0 && index < NUM_SERVOS);
}

int ServoController::getCurrentPosition(int servoIndex)
{
    if (isValidServoIndex(servoIndex))
    {
        return currentPositions[servoIndex];
    }
    return -1; // Invalid index
}

void ServoController::printStatus()
{
    Serial.println("=== Servo Status ===");
    for (int i = 0; i < NUM_SERVOS; i++)
    {
        Serial.print("Servo ");
        Serial.print(i);
        Serial.print(": ");
        Serial.println(currentPositions[i]);
    }
    Serial.println("==================");
}
